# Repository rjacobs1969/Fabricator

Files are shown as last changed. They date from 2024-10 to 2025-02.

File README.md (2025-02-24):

# The 3D Printer That Fits in a Billy: Solving Space Constraints in a small apartment

## Introduction
The struggle to balance my passion for 3D printing with the limited square footage of my apartment led to an innovative solution that maximized space and seamlessly integrated into my living environment. It all began with one of my favorite hobbies—3D printing. However, the constant battle for space in my apartment left me searching for a way to accommodate a 3D printer without sacrificing precious room. That’s when inspiration struck: I decided to design a 3D printer that would perfectly fit into one of the most ubiquitous pieces of furniture—the Ikea Billy bookcase.

## History
In 2016, I bought a Chinese 3D printer kit. After printing several upgrades, it transformed into a solid, albeit not very fast, machine with a 200x300x200 mm build volume. This size was sufficient for most of my projects. However, in 2020, with the arrival of a new family member, I lost my hobby room in our apartment, and finding space to store the printer became impossible. During the pandemic, it found a temporary home in the living area, where it printed face mask components to help meet the high demand.

## The Initial Solution
My initial solution was to design and create a small 3D-printed 3D printer that could be neatly stored in an Ikea Billy bookcase when not in use. This allowed me to disassemble and store my old, larger printer. While this compact printer, with its 10x10x10 cm build volume, was ingenious in terms of space-saving, its limited size made it suitable only for smaller projects.

## The Need for a Larger Solution
As time went on, I found myself needing to print larger items, some even exceeding the capacity of my original printer. This led me to design and build a new printer with specific characteristics: it had to fit in a Billy bookcase, reuse material from my old printer, have a minimum build volume of 200x400x200 mm, require minimal cabinet space, be corexy and Klipper-based, and feature a direct drive instead of a Bowden setup.

## The Innovative Design
The design I came up with is a fixed bed, moving/flying gantry core xy printer with an impressive build volume of 500x200x400 mm. The power supply and electronics are neatly located under the heated bed, which can be hinged like the hood of a car or easily removed by disconnecting just two connectors. With the bed fixed, the build volume can be utilized to store my small printer, resin printer, and filament dryer when not in use. This clever design means that the net space it occupies when not in use is just 10 cm from the bottom, 5 cm on each side, and 4 cm from the top of the cabinet.

## The Main Structural Elements
The main structural elements of my design are 2020 aluminum profiles, most of which are standard lengths to keep costs down and make sourcing easier. The bed is composed of two MK3S 200x280 aluminum beds, one of which came from my old printer. I created slicer profiles to use and heat the left, right, or both beds depending on the size of the object to be printed.

The gantry is upheld by four threaded rods connected to four stepper motors, allowing me to take advantage of the four-corner leveling built into Klipper. I opted to use linear rails for all axes: four MGN9 rails for the Z axis, two MGN9 rails for the Y axis, and one MGN12 rail for the X axis. This setup allows me to use toolheads designed for the VORON, although I am currently using a Chinese Ender 3 upgrade part. All printed parts were small enough to print on my mini printer, though many parts were later reprinted on the new printer to strengthen some components or redesign them for better clearance.

## Sharing the Design
After printing more than 20 kg of material over the last six months, I believe the design is solid enough to share with the community. I hope it can help others who, like me, love 3D printing but lack space for a typical 3D printer. I'm currently uploading the design files and instructions to my GitHub: [https://github.com/rjacobs1969/Fabricator/Build/Frame/BOM.md](./Build/Frame/BOM.md).

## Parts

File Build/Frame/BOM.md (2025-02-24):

## Gantry, Printer, and Bed Frame

- 6x 2020 profile 250mm
- 2x 2040 profile 250mm
- 2x 2060 profile 250mm
- 6x 2020 profile 500mm (note: my build used 550mm as the shop made a mistake)
- 1x 2020 profile 600mm
- 2x 2020 profile 680mm
- 2x 2040 profile 680mm

## Linear Rails

- 2x MGN9H 250mm
- 4x MGN9H 400mm
- 1x MGN12H 600mm

## Additional Components

- 8x Corner L plates

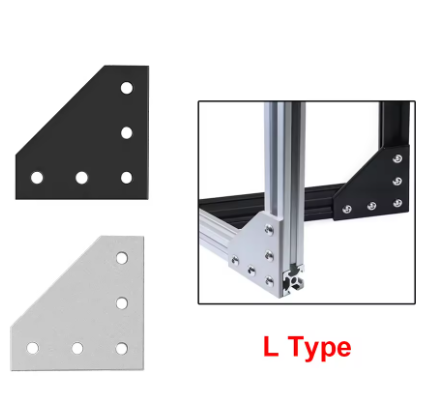
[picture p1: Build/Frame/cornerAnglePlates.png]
Corner L plates

- 8x Corner brackets

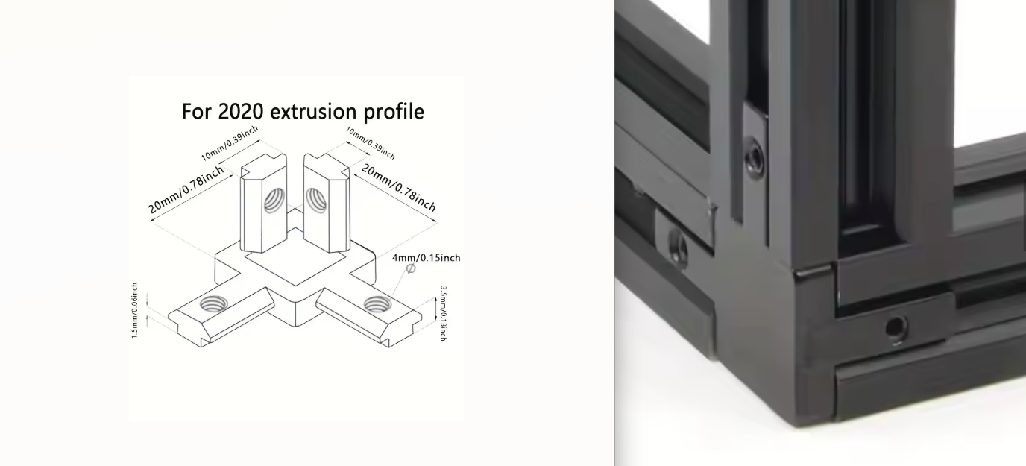
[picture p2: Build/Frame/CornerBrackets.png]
Corner brackets

- 8x Interior corner brackets

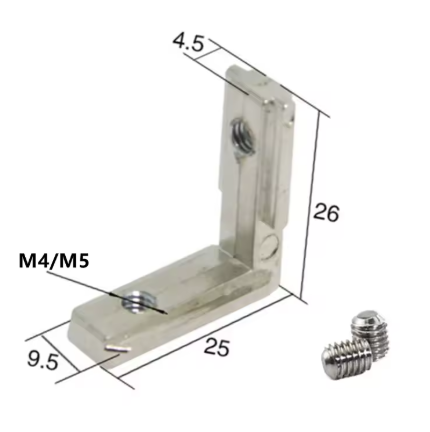
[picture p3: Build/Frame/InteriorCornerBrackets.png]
Interior corner brackets

- T-nuts or T-blocks (M3 for fixing the rails, M5 for everything else)

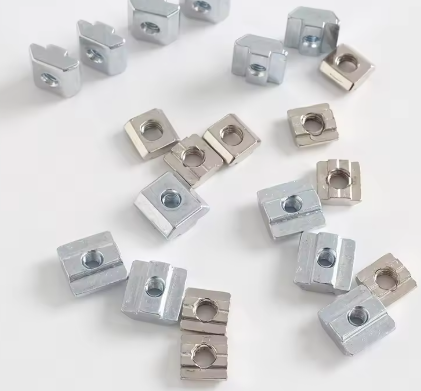
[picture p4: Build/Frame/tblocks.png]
T-nuts or T-blocks


##Next : [Assembly](Assembly.md)

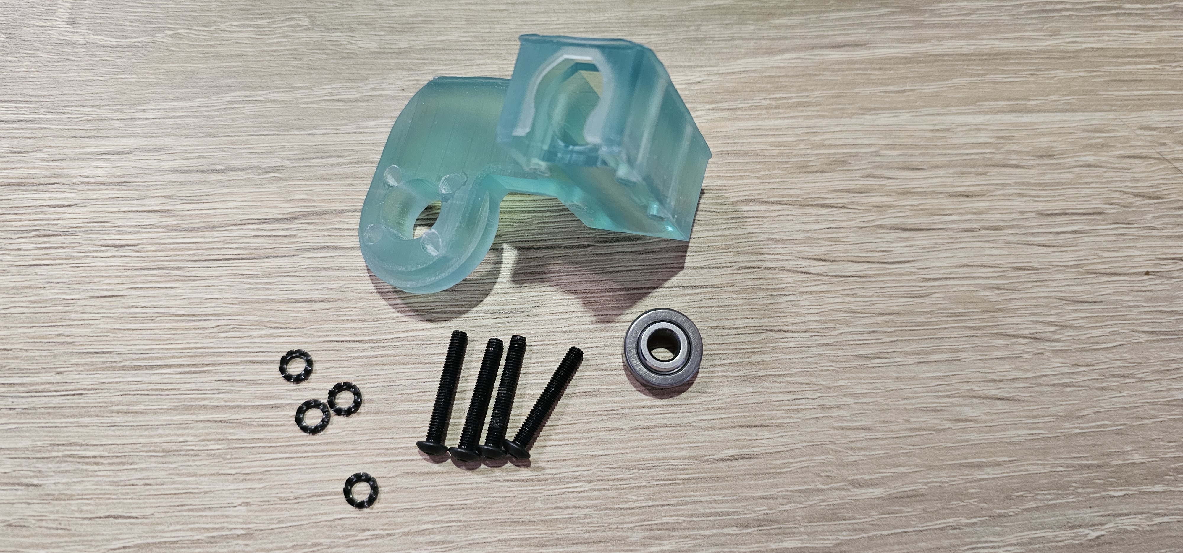
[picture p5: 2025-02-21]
Images/Y-Gantry/1parts.jpg

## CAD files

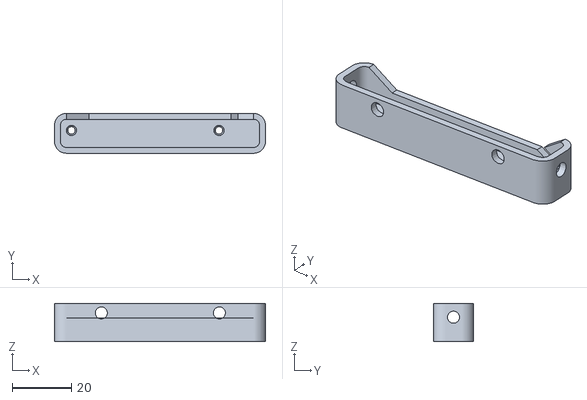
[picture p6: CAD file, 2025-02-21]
STL/Camera/CameraHousing.stl
71.5 x 13.6 x 13.0

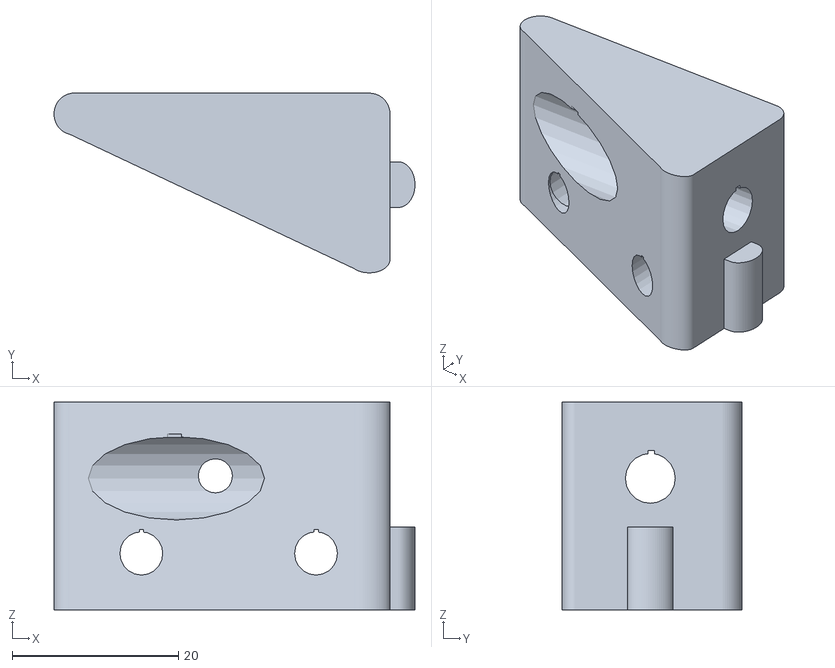
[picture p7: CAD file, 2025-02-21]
STL/MotorMounts/MotorMountsSupportLow_B.stl
43.4 x 21.6 x 25.0

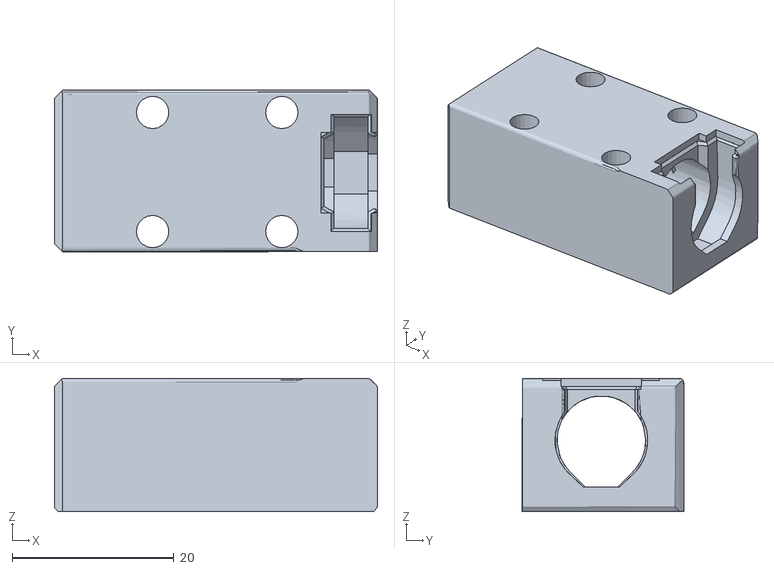
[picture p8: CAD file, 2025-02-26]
STL/Z-to-Y-mount.stl
40.0 x 20.0 x 16.5

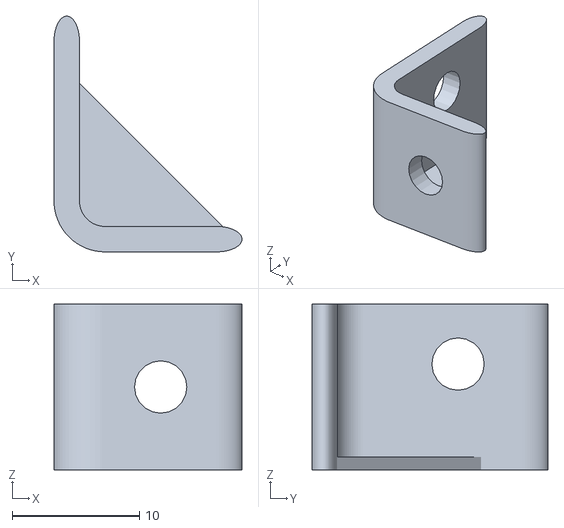
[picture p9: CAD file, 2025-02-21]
STL/Camera/CameraHousingMountB.stl
14.8 x 18.5 x 13.0

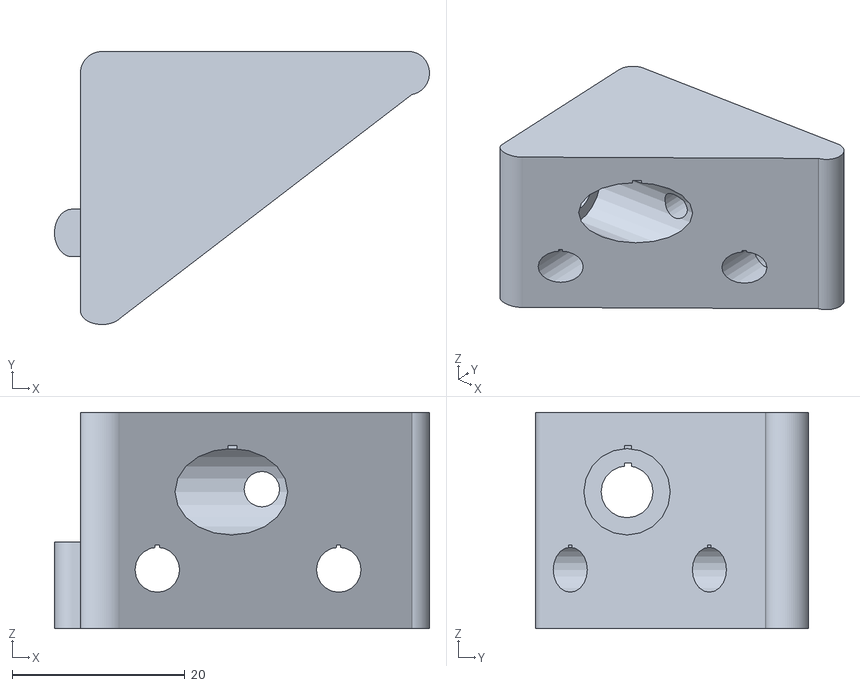
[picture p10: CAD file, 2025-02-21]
STL/MotorMounts/MotorMountsSupportHigh_B.stl
43.4 x 31.6 x 25.0

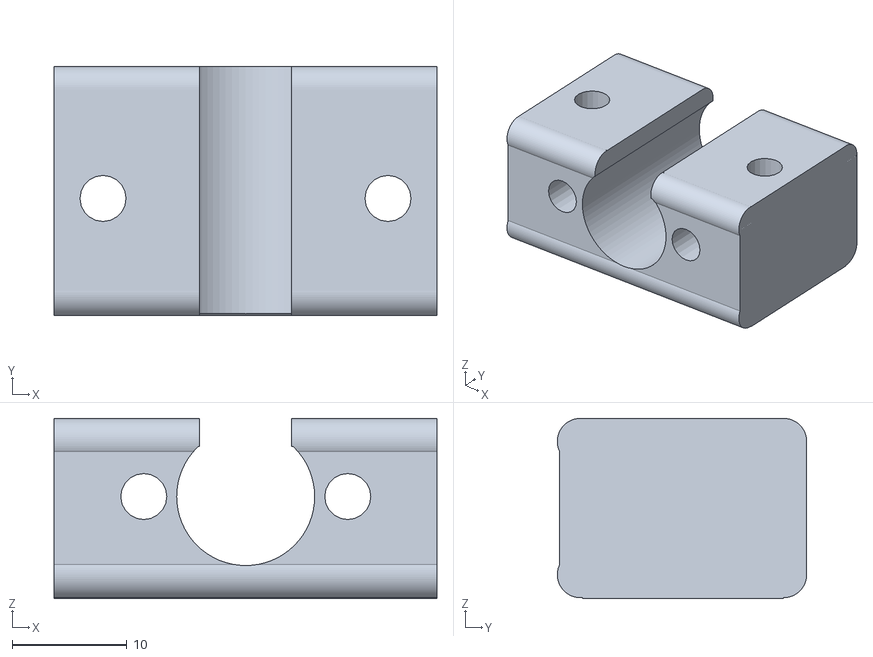
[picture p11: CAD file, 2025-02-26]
STL/oldhamCouplerMount.stl
33.3 x 21.7 x 15.7

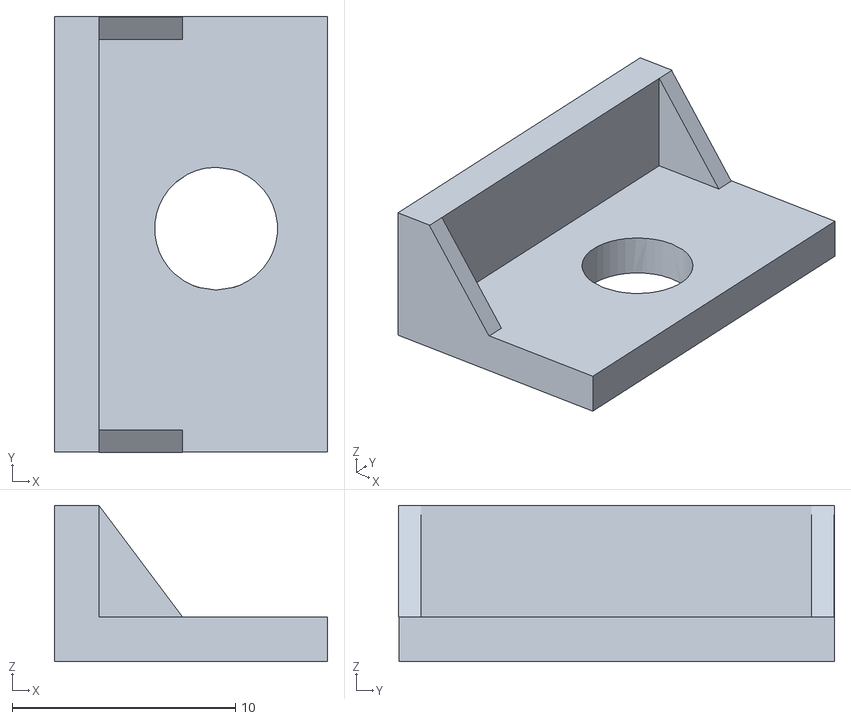
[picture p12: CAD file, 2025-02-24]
STL/endStop.stl
12.2 x 19.5 x 7.00

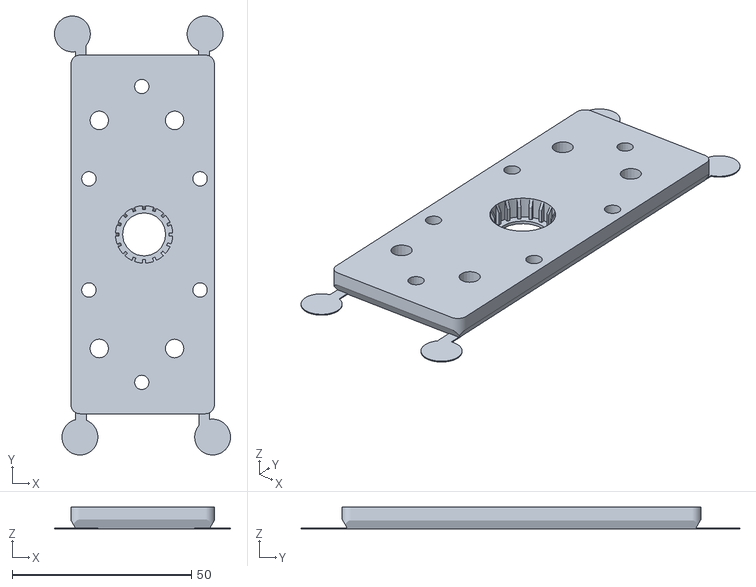
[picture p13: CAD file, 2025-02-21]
STL/MotorMounts/MotorMountsTopCover.stl
49.1 x 122.4 x 6.00

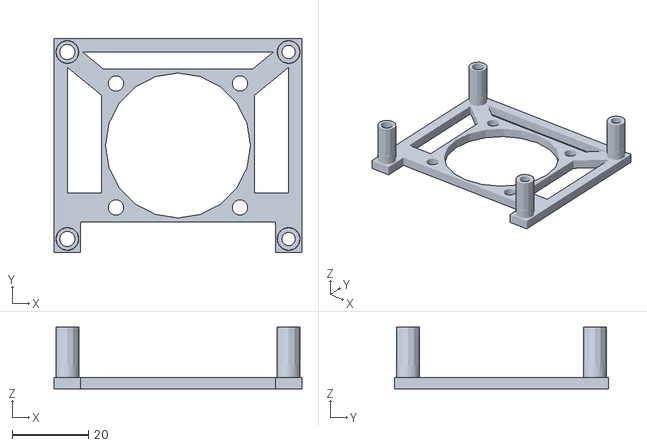
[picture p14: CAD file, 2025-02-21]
STL/PiFanMount.stl
65.0 x 56.0 x 16.2

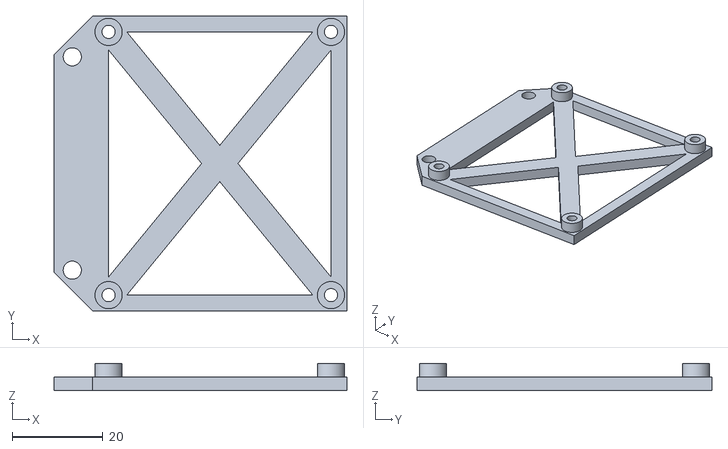
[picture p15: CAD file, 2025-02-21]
STL/Pi_Plate.stl
64.5 x 65.0 x 6.00

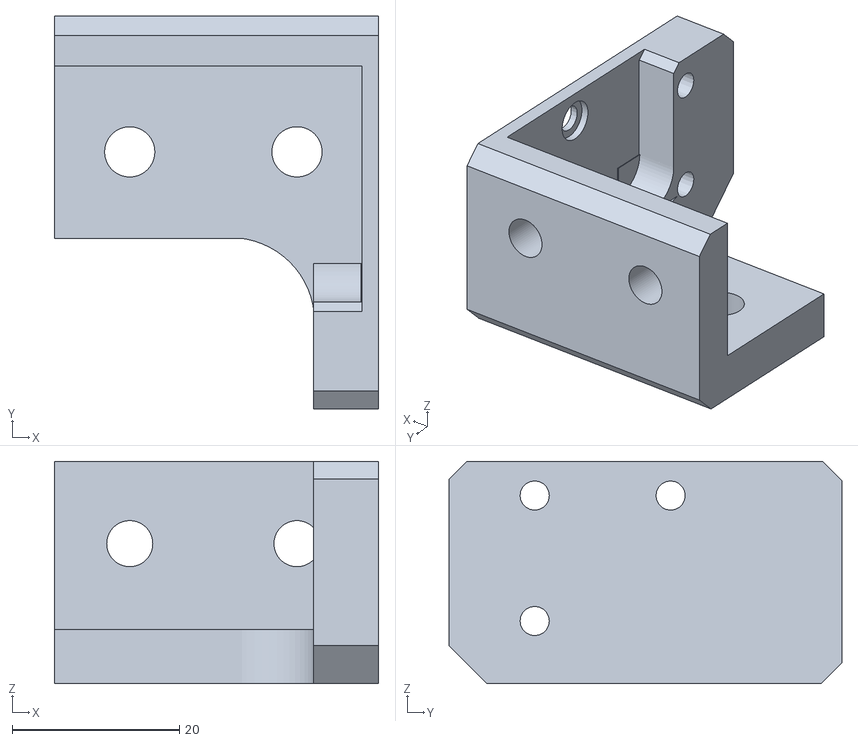
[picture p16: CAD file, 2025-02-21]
STL/gantryMountB.stl
38.8 x 47.0 x 26.6

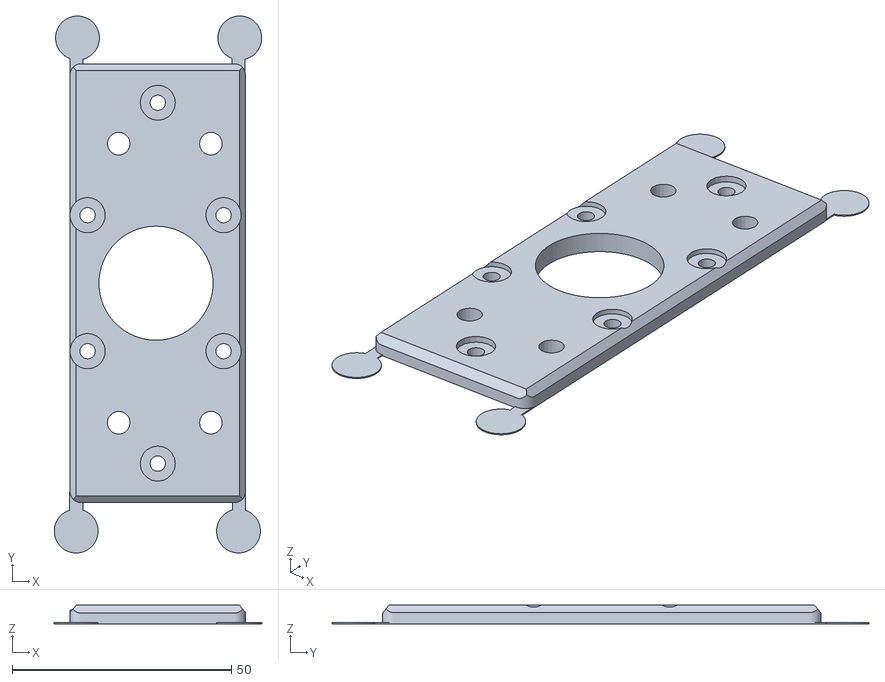
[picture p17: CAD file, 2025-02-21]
STL/MotorMounts/MotorMountsBasePlate.stl
47.3 x 122.4 x 4.25

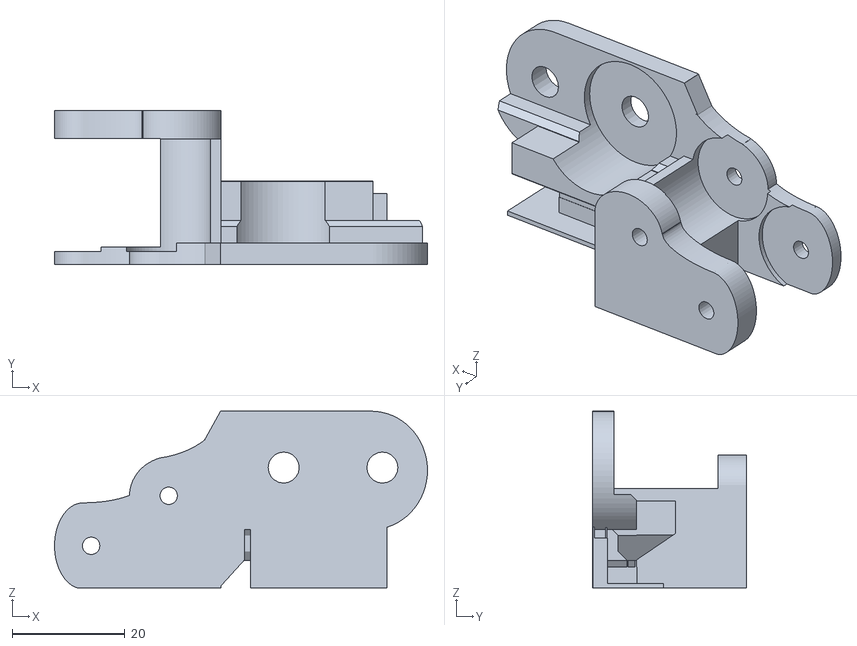
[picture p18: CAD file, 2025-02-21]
STL/PullyLV4a.stl
66.2 x 27.2 x 31.3

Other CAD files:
STL/Camera/CameraHousingMountA.stl
STL/MotorMounts/MotorMountsSupportHigh_A.stl
STL/MotorMounts/MotorMountsSupportLow_A.stl
STL/gantryMountA.stl
STL/PullyRV4a.stl
STL/beltClampShort.stl
STL/beltGuidesGantryA.stl
STL/beltGuidesGantryB.stl
STL/tensionerBlockM3.stl
STL/tensionerBlockM5.stl

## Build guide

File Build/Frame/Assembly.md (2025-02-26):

### FRAME Assembly

## Bottom
- 2X 2040 680mm profiles
- 2X 2020 250mm profiles
- 4x Corner brackets
- 4x Interior Corner Brackets (optional but recommended)

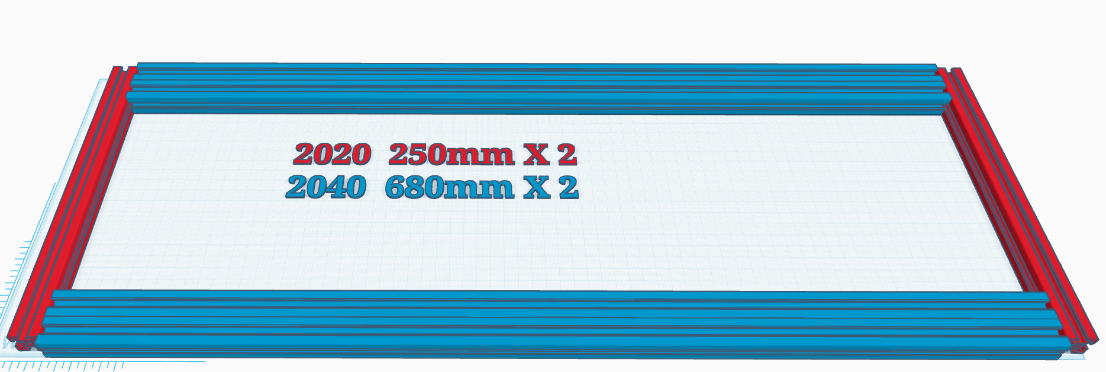
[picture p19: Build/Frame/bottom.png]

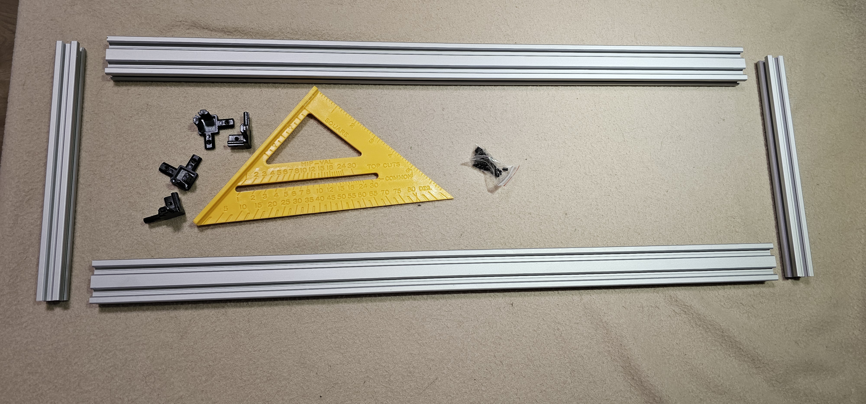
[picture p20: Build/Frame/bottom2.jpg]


Join the profiles with the corner brackets in such a way that the solid face of the corner brackets are in line with the short profiles, note not pictured are the recommended inner corner brackets as I added them at a later stage

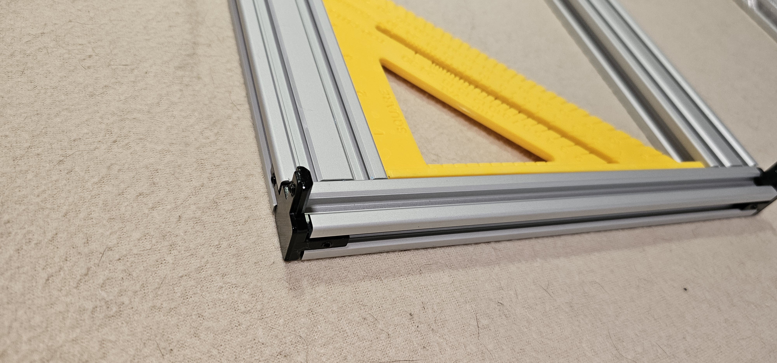
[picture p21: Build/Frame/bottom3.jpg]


## Top

- 2X 2020 680mm profiles
- 2X 2020 250mm profiles
- 4x Corner brackets
- 4x Interior Corner Brackets (optional but recommended)

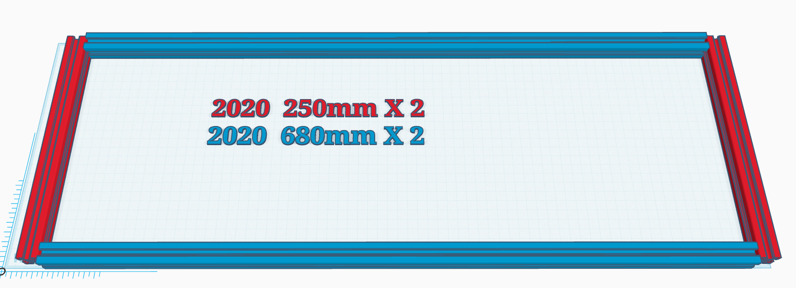
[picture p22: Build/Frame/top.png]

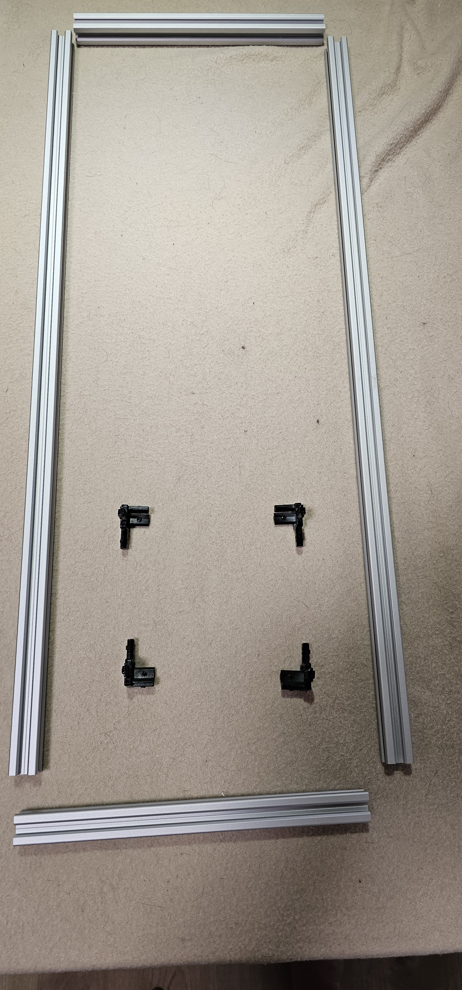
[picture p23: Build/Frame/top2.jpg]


Assemble in the same way as the bottom part

## Vertical

- 4X 2020 500mm profiles (or 550mm)
- 4X MGN9H 350 or 400mm rails
- 4X End of travel blocks (printed) [STL](../../STL/endStop.stl)

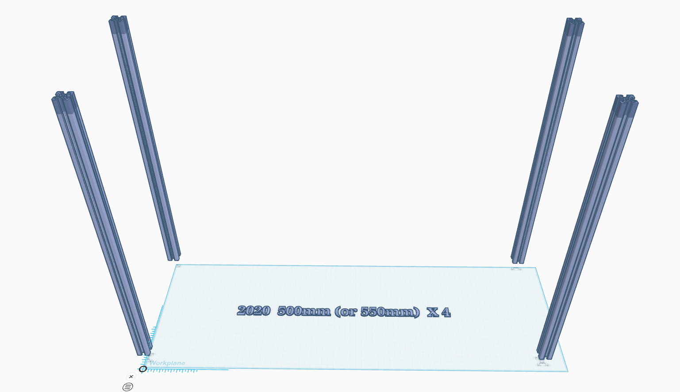
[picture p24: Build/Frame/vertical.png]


fix the vertical profiles to the bottom as pictured

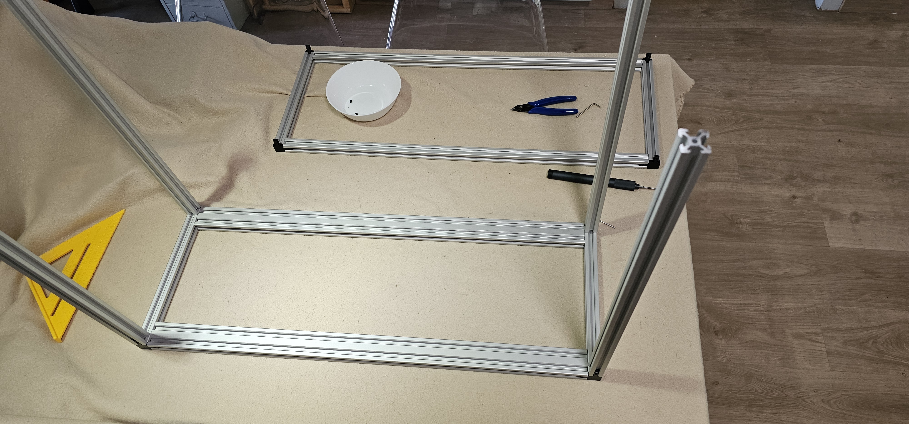
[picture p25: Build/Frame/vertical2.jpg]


Prepare the linear rails with t-blocks (t-nut can work too but I prefer the blocks)
I used a nut every third rail hole.

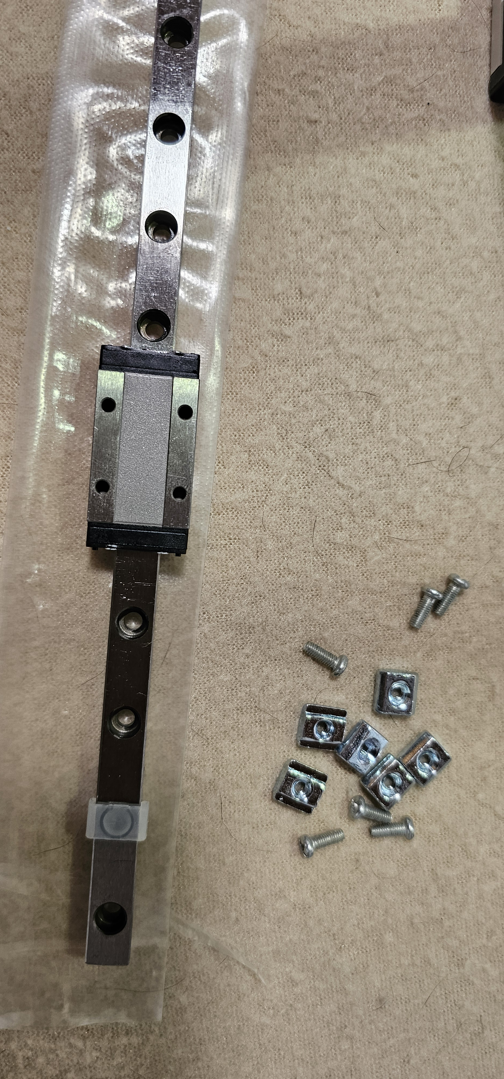
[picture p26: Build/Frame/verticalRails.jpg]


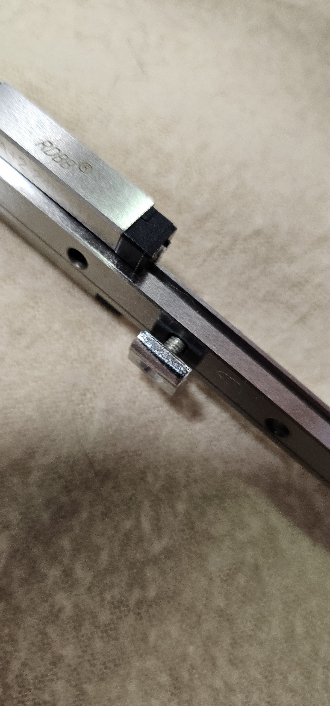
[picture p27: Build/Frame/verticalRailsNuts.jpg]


Slide the rails with nuts into the vertical profiles facing each other the long profile axis

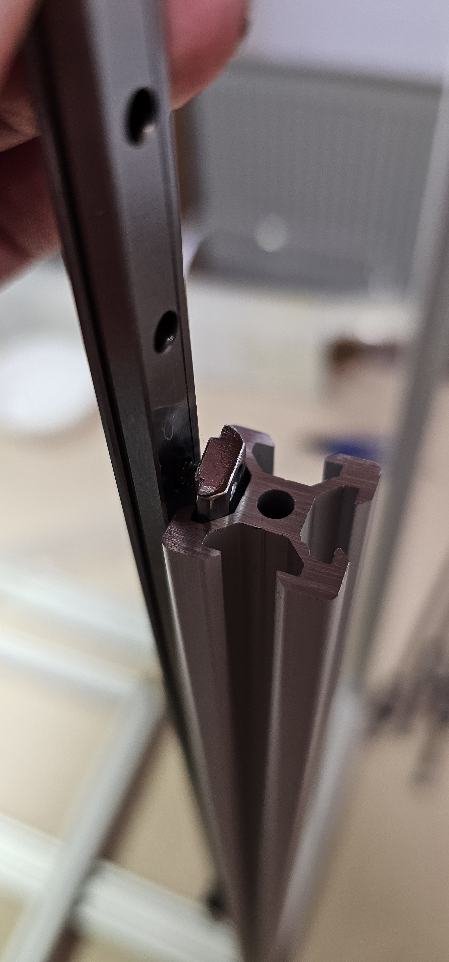
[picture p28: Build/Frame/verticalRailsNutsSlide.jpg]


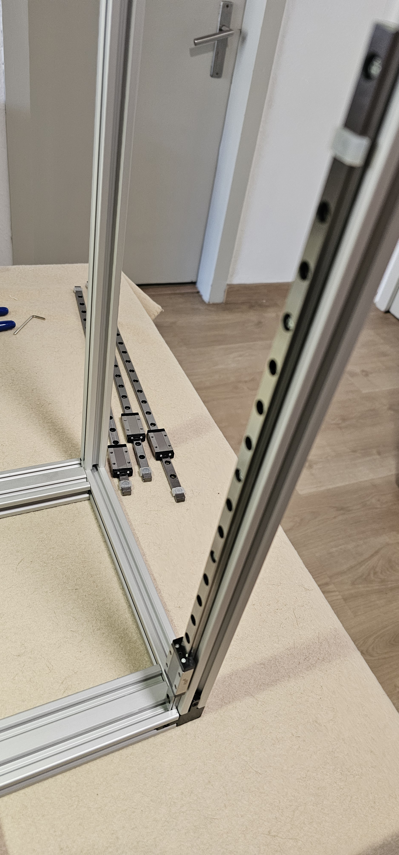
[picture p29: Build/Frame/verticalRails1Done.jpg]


Adjust the height of the rail to start 6cm from the bottom, hint: you can use the 2060 profile to do so

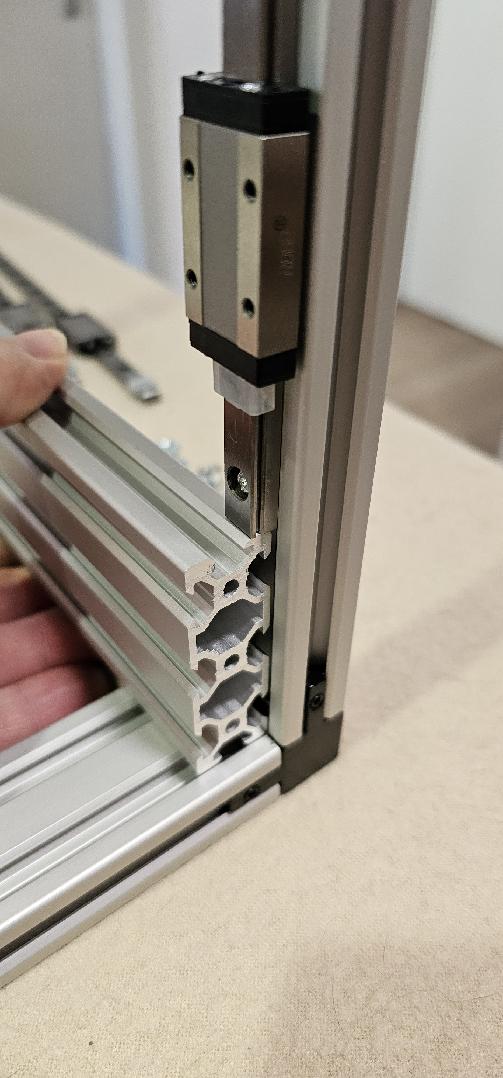
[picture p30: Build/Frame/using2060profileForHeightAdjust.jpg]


Add the Z-limits so the carriages cannot fall of the rails

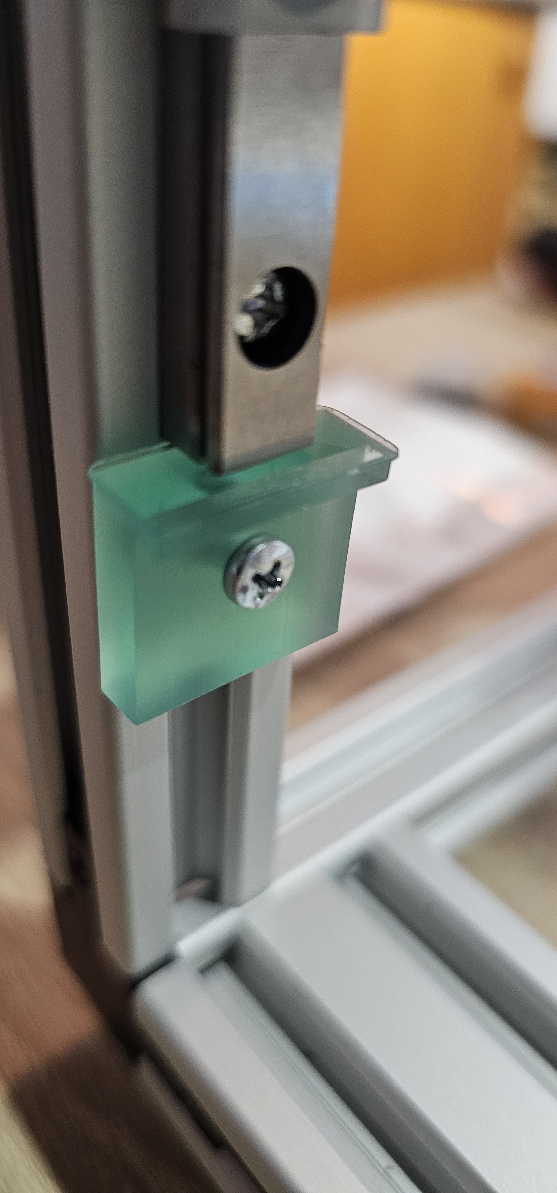
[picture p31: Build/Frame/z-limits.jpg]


Fix the top frame to the rest of the frame

## Z-Motors mount

- 2X 2040 250mm profile
- 4X Nema17 34mm height stepper motors
- 4X Nema17 Bracket Aluminum Plate
- 4x 60mm 3 hole 2020 mounting plates and 5mm spacers

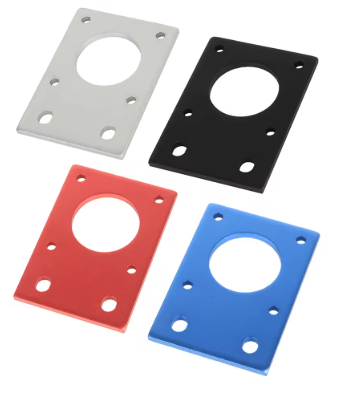
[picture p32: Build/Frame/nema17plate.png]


Fix the motors to the plates, note the connector of the stepper wires should be on the side

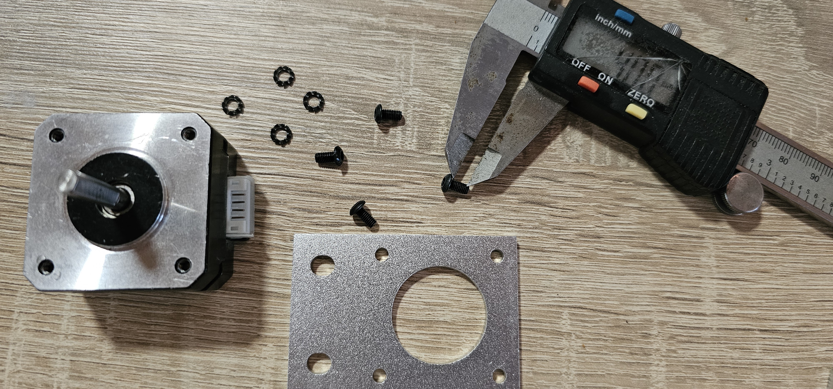
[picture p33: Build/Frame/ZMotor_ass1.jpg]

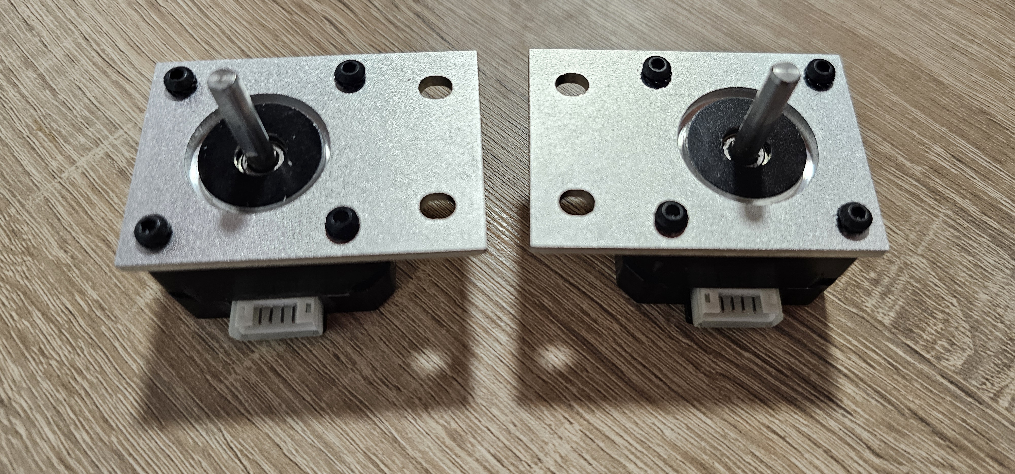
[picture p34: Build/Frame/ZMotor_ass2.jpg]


Fix the plates to the profile (using M5 t-blocks/nuts and bolts) make sure the connectors of the stepper wires
face each other as pictured

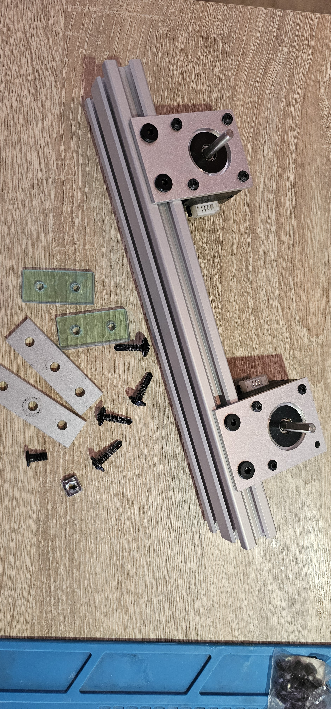
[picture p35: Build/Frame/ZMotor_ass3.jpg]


Fix the profile to the frame, the motors should just touch the vertical profiles
of the frame and the backside should be flush the sides of the printer,
do so for the left as well as the right side of the printer

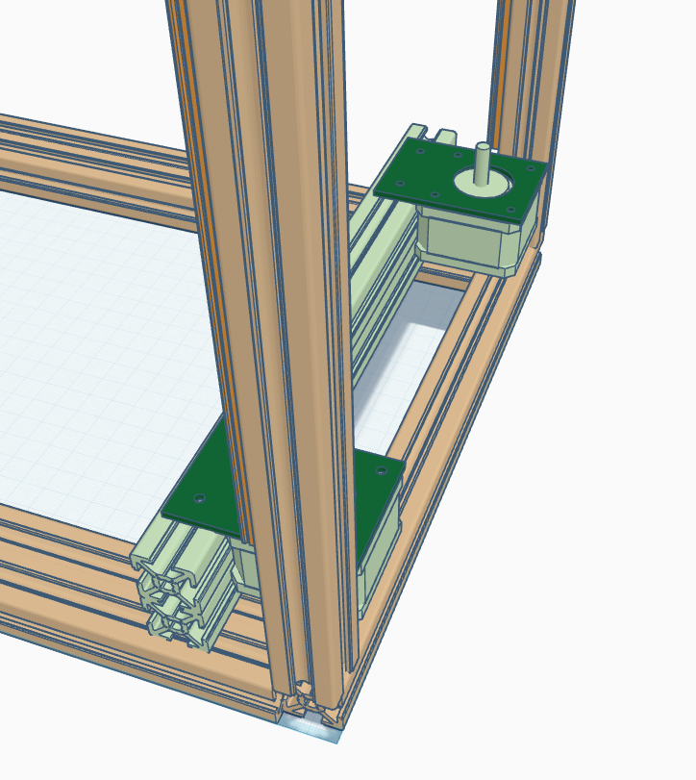
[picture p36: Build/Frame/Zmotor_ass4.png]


## Next : [Assembly of the bed frame](BedFrameAssembly.md)

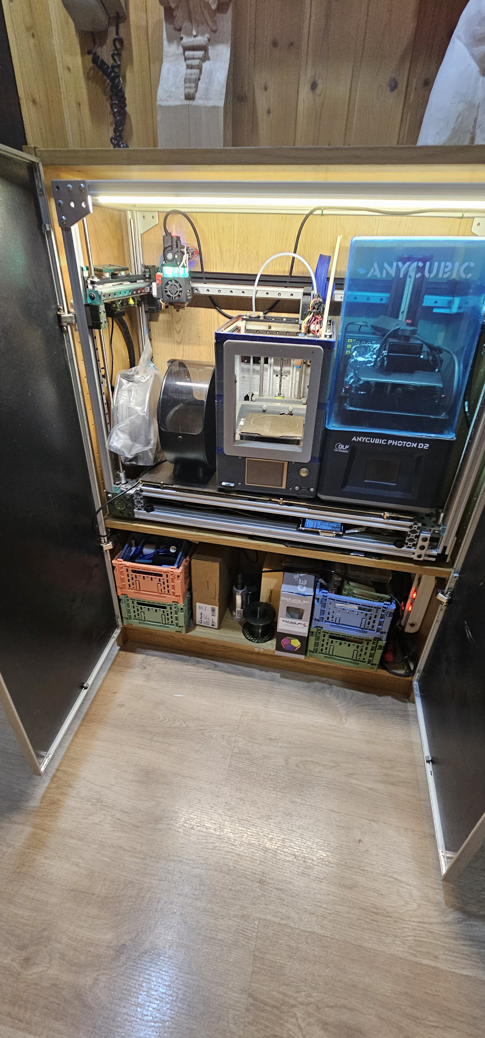
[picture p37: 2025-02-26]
Images/printersWithinPrinter.jpg

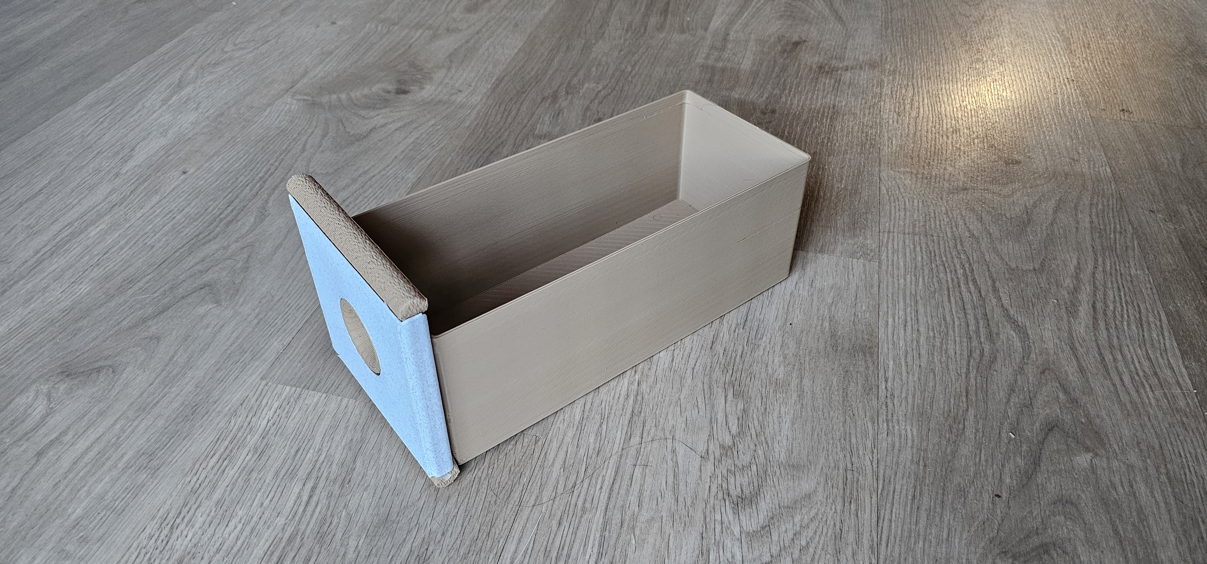
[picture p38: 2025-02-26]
Images/3dPrinterDrawer50cm length2.jpg

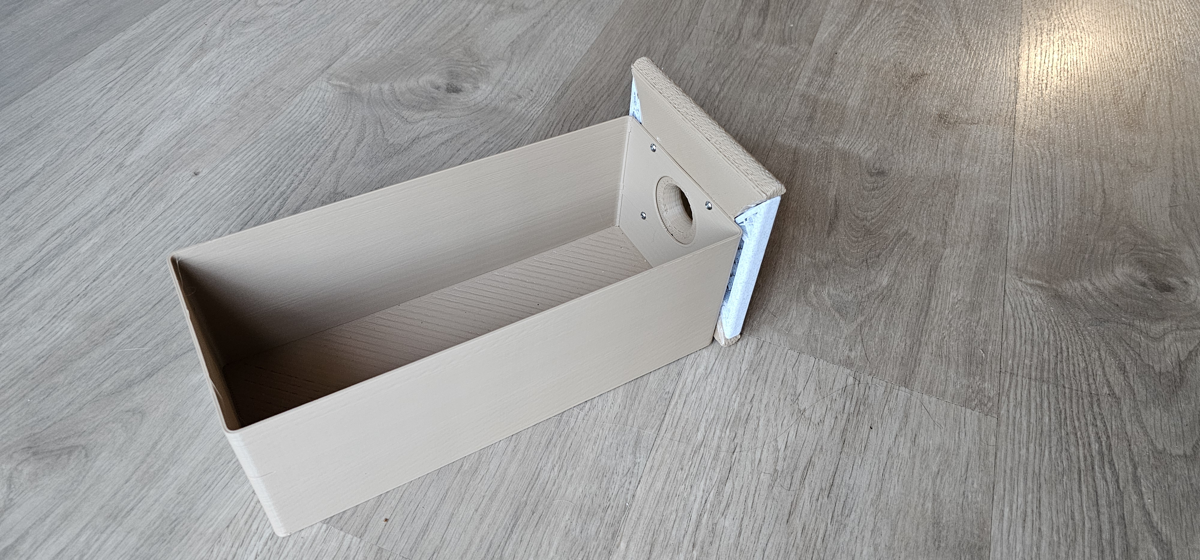
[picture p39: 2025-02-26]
Images/3dPrinterDrawer50cm length.jpg

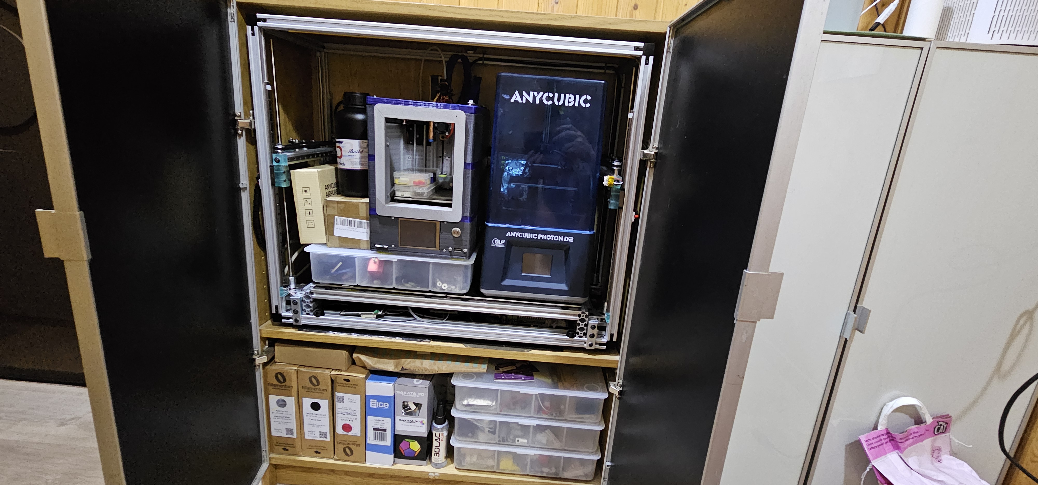
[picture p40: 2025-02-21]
Images/tthreePrintersPlusSupplies.jpg

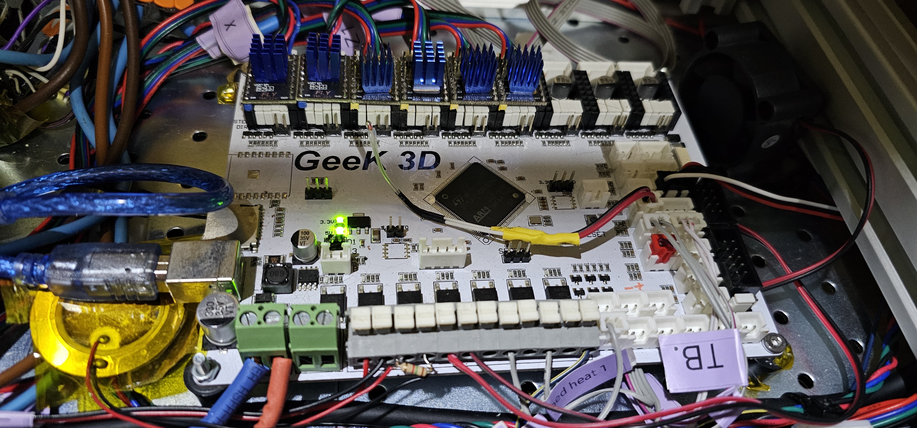
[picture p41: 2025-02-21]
Images/9channelPrinterPCB.jpg

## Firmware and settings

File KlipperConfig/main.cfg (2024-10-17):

# "FLYF407ZG" board from mellow. To
# use this config, the firmware should be compiled for the STM32F407
# with a "32KiB bootloader".

# The "make flash" command does not work on the FLYBOARD. Instead,
# after running "make", copy the generated "out/klipper.bin" file to a
# file named "firmware.bin" on an SD card and then restart the FLYBOARD
# with that SD card.

# See docs/Config_Reference.md for a description of parameters.

[mcu]
serial: /dev/serial/by-id/usb-Klipper_stm32f407xx_2C00250007504E344E383720-if00

[heater_generic bed_left]
heater_pin: PF6 #heater1
sensor_type: Generic 3950
sensor_pin: PF5
control: pid
pid_Kp: 71.522  # calibrated on left bed 8/10/2024
pid_Ki: 1.697
pid_Kd: 753.662
min_temp: 15    # Minimum temperature the bed can be set to.
max_temp: 100   # Maximum temperature the bed can be set to.

[heater_generic bed_right]
gcode_id: 1
heater_pin: PE6
sensor_pin: PF4
sensor_type: Generic 3950
control: pid
pid_Kp: 71.522  # calibrated on left bed 8/10/2024
pid_Ki: 1.697
pid_Kd: 753.662
min_temp: 15    # Minimum temperature the bed can be set to.
max_temp: 100   # Maximum temperature the bed can be set to.

[stepper_x]
step_pin: PB9
dir_pin: !PE0
enable_pin: !PE1
microsteps: 16
rotation_distance: 32
#endstop_pin: !PC3
endstop_pin: !SHT36PRO:gpio26  # in reality, this is the thermistor pin on the SHT36PRO
position_endstop: 2.0
position_min: 0
position_max: 485 # temporary restriction due to clearance issues on gantry, final will be about 520
homing_speed: 50
homing_retract_dist: 5.0
homing_retract_speed: 50
second_homing_speed: 25
#homing_positive_dir: false

[stepper_y]
step_pin: PB8
dir_pin: !PG11
enable_pin: !PG12
microsteps: 16
rotation_distance: 32
endstop_pin: PF2
position_endstop: -1
position_min: -2
position_max: 200
homing_speed: 50
homing_retract_dist: 5.0
homing_retract_speed: 50
second_homing_speed: 25



[stepper_z1]
step_pin: PC7
dir_pin: PD3
enable_pin: !PD4
microsteps: 16
rotation_distance: 8

[stepper_z2]
step_pin: PC6
dir_pin: PA15
enable_pin: !PD0
microsteps: 16
rotation_distance: 8

[stepper_z3]
step_pin: PD15
dir_pin: PG7
enable_pin: !PG8
microsteps: 16
rotation_distance: 8

################################################
# TMC2240 configuration for X and Y axis
################################################

[tmc2240 stepper_x]
cs_pin: PG13
run_current: 1.5 # rated 2.5A, recommended = 60% of rated current
hold_current: 0.75
stealthchop_threshold: 999999
rref: 12300
interpolate: false
##diag1_pin: PC3
diag0_pin: ^!PC3
driver_SGT: 1

[tmc2240 stepper_y]
cs_pin: PG10
run_current: 1.5 # rated 2.5A, recommended = 60% of rated current
hold_current: 0.75
stealthchop_threshold: 999999
rref: 12300
interpolate: false
##diag1_pin: PF2
diag0_pin: ^!PF2
driver_SGT: 1

################################################
# TMC2130 configuration for Z axis and extruders
#
# Z axis uses 4 TMC2130 drivers, one for each 17HS2408 motor.
# Extruders use 3 TMC2130 drivers, one for each 17HD4401 motor.
# The TMC2130 drivers are configured to use the SPI interface.
#
# 17HS2408:
# 1.8 degree, 200 step/rev motors.
# Holding Torque: 12Ncm
# Rated Current: 0.6A
#
# 17HD4401/17HS4401:
# 1.8 degree, 200 step/rev motors.
# Holding Torque: 24Ncm
# Rated Current: 1.68A
################################################

[tmc2130 stepper_z]
cs_pin: PD5
##diag1_pin: PF0
run_current: 0.40
hold_current: 0.250
stealthchop_threshold: 999999

[tmc2130 stepper_z1]
cs_pin: PD1
##diag1_pin: PE15
run_current: 0.400
hold_current: 0.250
stealthchop_threshold: 999999

[tmc2130 stepper_z2]
cs_pin: PA14
##diag1_pin: PE10
run_current: 0.400
hold_current: 0.250
stealthchop_threshold: 999999

[tmc2130 stepper_z3]
cs_pin: PG6
##diag1_pin: PC15
run_current: 0.400
hold_current: 0.250
stealthchop_threshold: 999999

[temperature_fan bottom_case_fan]
pin: PE3
max_power: 1.0
shutdown_speed: 1.0
kick_start_time: 0.5
off_below: 0.25
sensor_pin: PF10
sensor_type: Generic 3950
control:watermark
target_temp: 30
min_temp: 0
max_temp: 70

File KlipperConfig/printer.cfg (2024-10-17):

[include mainsail.cfg]
[include fluidd.cfg]
[include FlyPi.cfg]
[include main.cfg]
[include SHT36PRO.cfg]
[include Orbiter2_SmartSensor.cfg]
[include macros.cfg]
[include bedHeaters.cfg]

[virtual_sdcard]
path: /home/fly/printer_data/gcodes
on_error_gcode: CANCEL_PRINT

[printer]
kinematics: corexy
max_velocity: 300
max_accel: 3000
max_z_velocity: 15
max_z_accel: 100

[stepper_x]
step_pin: PB9
dir_pin: !PE0
enable_pin: !PE1
microsteps: 16
rotation_distance: 32
#endstop_pin: !PC3
endstop_pin: !SHT36PRO:gpio26  # in reality, this is the thermistor pin on the SHT36PRO
position_endstop: 2.0
position_min: 0
position_max: 485 # temporary restriction due to clearance issues on gantry, final will be about 520
homing_speed: 50
homing_retract_dist: 5.0
homing_retract_speed: 50
second_homing_speed: 25
#homing_positive_dir: false

[stepper_y]
step_pin: PB8
dir_pin: !PG11
enable_pin: !PG12
microsteps: 16
rotation_distance: 32
endstop_pin: PF2
position_endstop: -1
position_min: -2
position_max: 200
homing_speed: 50
homing_retract_dist: 5.0
homing_retract_speed: 50
second_homing_speed: 25

[stepper_z]
step_pin: PA8
dir_pin: PD6
enable_pin: !PD7
microsteps: 16
rotation_distance: 8
#endstop_pin: PF0
endstop_pin: probe:z_virtual_endstop
#position_endstop: -1.4
position_min: -2
position_max: 300.0

[safe_z_home]
home_xy_position: 110, 100
speed: 50
z_hop: 5
z_hop_speed: 15

[stepper_z1]
step_pin: PC7
dir_pin: PD3
enable_pin: !PD4
microsteps: 16
rotation_distance: 8

[stepper_z2]
step_pin: PC6
dir_pin: PA15
enable_pin: !PD0
microsteps: 16
rotation_distance: 8

[stepper_z3]
step_pin: PD15
dir_pin: PG7
enable_pin: !PG8
microsteps: 16
rotation_distance: 8

#####################################################################
# extruder: Orbiter 2
#####################################################################
[extruder]
step_pin: SHT36PRO:gpio23
dir_pin: !SHT36PRO:gpio24
enable_pin: !SHT36PRO:gpio25
microsteps:16
full_steps_per_rotation: 200
rotation_distance: 4.637
nozzle_diameter:0.600
filament_diameter:1.75
max_extrude_only_distance:500
max_extrude_only_velocity:120
pressure_advance: 0.075 # TODO, must be calibrated https://www.klipper3d.org/zh/Pressure_Advance.html
pressure_advance_smooth_time: 0.040 # TODO, must be calibrated
heater_pin: SHT36PRO:gpio8
min_temp: 10
max_temp: 450
max_power: 1.0
min_extrude_temp: 150

[quad_gantry_level]
gantry_corners:
    -110,40
    570,220
#   A newline separated list of X, Y coordinates describing the two
#   opposing corners of the gantry. The first entry corresponds to Z,
#   the second to Z2. This parameter must be provided.
points:
    5,20
    5,200
    485,200
    485,20
#   A newline separated list of four X, Y points that should be probed
#   during a QUAD_GANTRY_LEVEL command. Order of the locations is
#   important, and should correspond to Z, Z1, Z2, and Z3 location in
#   order. This parameter must be provided. For maximum accuracy,
#   ensure your probe offsets are configured.
#   note: the coordinates are of the nozzle, not the probe.
speed: 100
#   The speed (in mm/s) of non-probing moves during the calibration.
#   The default is 50.
horizontal_move_z: 10
#   The height (in mm) that the head should be commanded to move to
#   just prior to starting a probe operation. The default is 5.
max_adjust: 25
#   Safety limit if an adjustment greater than this value is requested
#   quad_gantry_level will abort.
retries: 5
#   Number of times to retry if the probed points aren't within
#   tolerance.
retry_tolerance: 0.05
#   If retries are enabled then retry if largest and smallest probed
#   points differ more than retry_tolerance.

# BIGTREETECH MicroProbe
[probe]
pin: ^!SHT36PRO:gpio3
deactivate_on_each_sample: False
x_offset: -40
y_offset: 4
#z_offset: 2.79  # Will be overridden when you do a PROBE_CALIBRATE
samples: 2
samples_tolerance: 0.05
samples_tolerance_retries: 3
activate_gcode:
    PROBE_DOWN
    G4 P500
deactivate_gcode:
    PROBE_UP

[bed_mesh]
speed: 150
horizontal_move_z: 5
mesh_min: -35,20
mesh_max: 440,180
probe_count: 9, 4
algorithm: bicubic
fade_start: 0.6
fade_end: 10
fade_target: 0

########################################
# EXP1 / EXP2 (display) pins
########################################

[board_pins]
aliases:
    # EXP1 header
    EXP1_1=PB10, EXP1_3=PE14, EXP1_5=PE10, EXP1_7=PE8, EXP1_9=<GND>,
    EXP1_2=PE15, EXP1_4=PE12, EXP1_6=PE9,  EXP1_8=PE7, EXP1_10=<5V>,
    # EXP2 header
    EXP2_1=PB14, EXP2_3=PC5,  EXP2_5=PC4,  EXP2_7=PB2,   EXP2_9=<GND>,
    EXP2_2=PB13, EXP2_4=PF11, EXP2_6=PB15, EXP2_8=<RST>, EXP2_10=<GND>
    # Pins EXP2_1, EXP2_6, EXP2_2 are also MISO, MOSI, SCK of bus "spi2"

# See the sample-lcd.cfg file for definitions of common LCD displays.

#*# <---------------------- SAVE_CONFIG ---------------------->
#*# DO NOT EDIT THIS BLOCK OR BELOW. The contents are auto-generated.
#*#
#*# [probe]
#*# z_offset = 0.430
#*#
#*# [bed_mesh default]
#*# version = 1
#*# points =
#*# 	  0.108750, 0.145000, 0.150000, 0.242500, 0.297500, 0.201250, 0.145000, 0.117500, 0.063750
#*# 	  -0.027500, -0.005000, 0.047500, 0.101250, 0.136250, 0.091250, 0.046250, 0.006250, -0.035000
#*# 	  -0.055000, -0.035000, 0.006250, 0.058750, 0.078750, 0.062500, 0.031250, 0.011250, -0.040000
#*# 	  -0.053750, -0.026250, 0.048750, 0.115000, 0.153750, 0.128750, 0.095000, 0.083750, 0.016250
#*# x_count = 9
#*# y_count = 4
#*# mesh_x_pps = 2
#*# mesh_y_pps = 2
#*# algo = bicubic
#*# tension = 0.2
#*# min_x = -35.0
#*# max_x = 439.96
#*# min_y = 20.0
#*# max_y = 179.99

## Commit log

2025-02-24 BOM, Images
2025-02-24 More docs
    [endStop.stl]
2025-02-26 zmotor mounts
2025-02-26 more files
    [Z-to-Y-mount.stl, oldhamCouplerMount.stl]
